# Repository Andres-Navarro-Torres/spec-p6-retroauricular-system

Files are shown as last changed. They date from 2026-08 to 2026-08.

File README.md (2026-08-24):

# SPEC-P6: An Open-Source, Modular, and Synchronized Wearable Sensor Platform



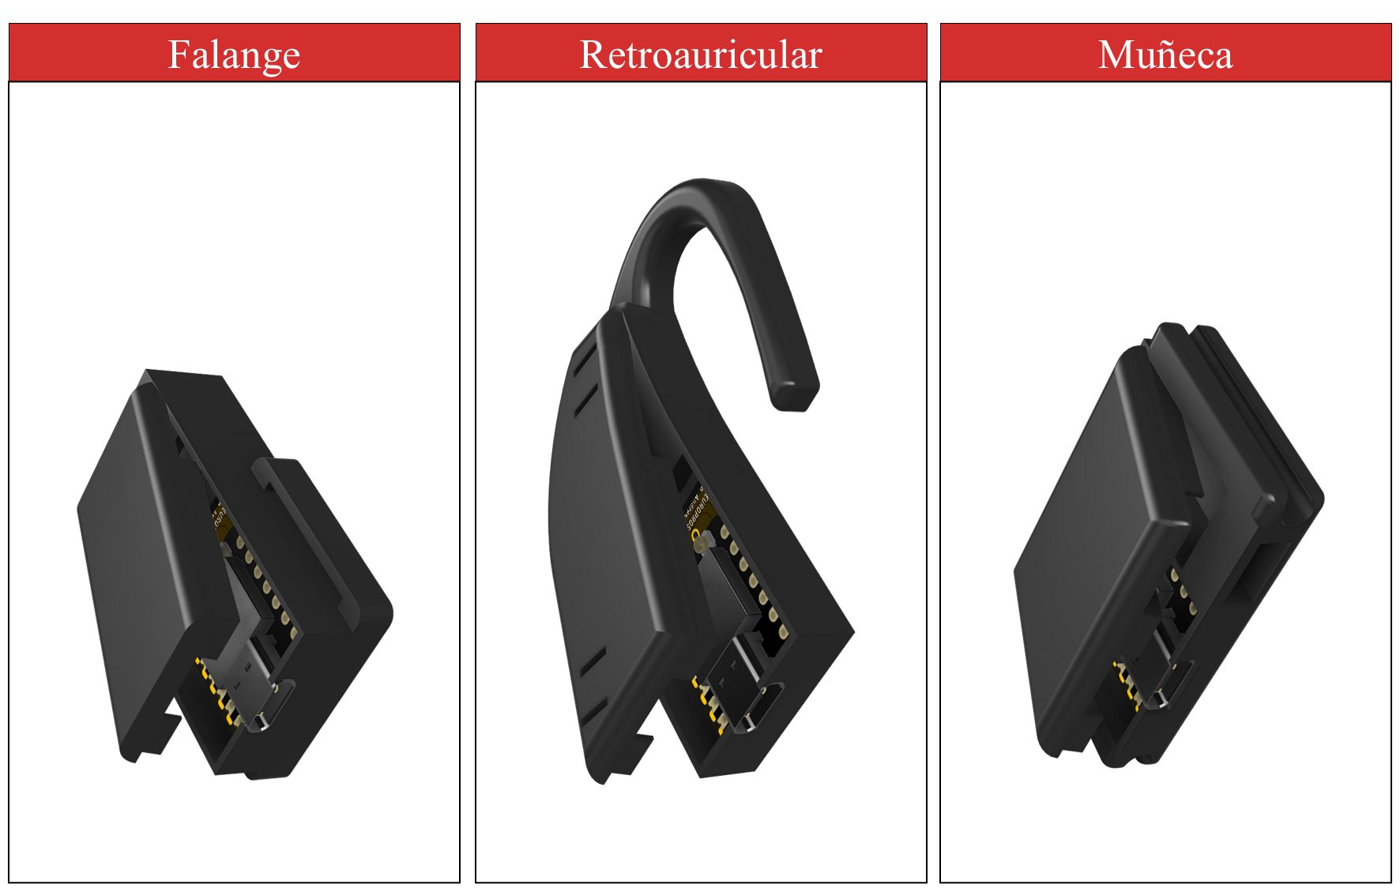
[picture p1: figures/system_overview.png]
SPEC-P6 System Overview
 

## Overview

SPEC-P6 is an open-source, reproducible, and modular wearable platform designed for simultaneous, multi-site acquisition of photoplethysmography (PPG) and inertial measurement unit (IMU) data. The system enables synchronized telemetry across multiple anatomical locations (specifically configured for the retroauricular region, wrist, and index finger) using a wireless star network architecture.

## System Architecture

The platform operates under a star network topology where a central Coordinator gathers data packets from multiple wearable Sensor Nodes via ESP-NOW and forwards them to a host computer through a high-speed serial link:

`PC (Python GUI) <-> Serial (921,600 baud) <-> Coordinator (ESP32) <-> ESP-NOW <-> Sensor Nodes (XIAO ESP32-C6)`

- **Sensor Node (Custom Hardware):** A compact custom PCB integrating a Seeed Studio XIAO ESP32-C6, a MAX30102 PPG sensor, an MPU6050 6-axis IMU, LDO voltage regulators, a 3.7V 100 mAh LiPo battery, and power management switches.
- **Coordinator (Functional Role):** A standard COTS ESP32 development board running firmware that bridges wireless ESP-NOW telemetry to a serial stream. It also provides a hardware digital/TTL synchronization trigger (Pin 2) for precise time-alignment with external DAQ systems (e.g., BIOPAC).

## Repository Structure

The repository is organized into the following directories:

- `/hardware/`: Contains custom PCB Gerber files, EAGLE source files (`.sch`, `.brd`), and the detailed Bill of Materials (BOM) with manufacturer part numbers.
- `/mechanical/`: Includes 3D printable `.STL` files and editable CAD source files for the wearable enclosures across all targeted anatomical sites.
- `/firmware/`: Houses the C/C++ source code for the Sensor Nodes and the Coordinator, alongside shared MAC address definitions.
- `/software/`: Contains the Python-based graphical acquisition suite (`spec_p6_acquisition_suite.py`), battery logging utilities, and `requirements.txt`. The GUI utilizes PyQt6 and PyQtGraph for high-performance rendering, and SciPy for real-time digital filtering of the raw signals.
- `/documentation/`: Contains printing guidelines (`PRINTING_SETTINGS.md`) and component assembly instructions.
- `/figures/`: High-resolution images of the hardware, GUI screenshots, and in-vivo placement examples.
- `/protocols/`: Markdown files describing acquisition, communication, and synchronization procedures.
- `/validation/`: Includes a sample dataset (`.csv`) for script testing and battery discharge logs.

## Key Technical Specifications

- **Target Sampling Rate:** 50 Hz steady for both PPG and IMU streams.
- **Wireless Protocol:** ESP-NOW (packaged in batches of 5 samples per transmission to optimize network bandwidth).
- **Concurrency:** FreeRTOS-based multitasking on the ESP32-C6 core for robust sensor polling and transmission without timing jitter.
- **Battery Life:** ~58 minutes of continuous multi-sensor transmission on a 100 mAh LiPo cell.
- **Timing Performance:** Low jitter (< 0.6 ms) and zero packet loss under standard laboratory testing conditions.

## Quick Start & Reproduction Guide

To deploy and operate the SPEC-P6 platform:

1. **Hardware Fabrication:** Order the PCB using the Gerber files in `/hardware/` and assemble following the BOM guidelines.
2. **Firmware Flashing:** 
   - Flash `coordinator.ino` onto your Coordinator ESP32 device.
   - Flash `sensor_node.ino` onto your XIAO ESP32-C6 nodes, ensuring MAC addresses are correctly mapped in the firmware definitions.
3. **Mechanical Enclosures:** Print the 3D cases located in `/mechanical/STL_files/`. Refer to `/documentation/PRINTING_SETTINGS.md` for specific Bambu Lab slicing parameters (TPU/PETG recommendations).
4. **Software Execution:** 
   - Install Python dependencies via `pip install -r software/requirements.txt`.
   - Run the acquisition suite using `python software/spec_p6_acquisition_suite.py`.

## How to Cite

If you use SPEC-P6 in your academic research, please cite it using the repository's DOI:

> Navarro-Torres, A., Rosas-Agraz, F., Vélez-Pérez, H. A., Romo-Vázquez, R., & Guzmán-Quezada, E. E. (2026). SPEC-P6: An open-source synchronized wearable platform for multisite photoplethysmography and inertial sensing. Zenodo. https://doi.org/10.5281/zenodo.22048827

See the `CITATION.cff` file for more details.

## License

To effectively cover both the software and physical hardware designs, this project employs a dual-licensing strategy:

- **Software and Firmware:** Licensed under the [MIT License](LICENSE-SOFTWARE).
- **Hardware and Mechanical Designs:** Licensed under the CERN Open Hardware Licence Version 2 - Weakly Reciprocal (CERN-OHL-W-v2). You may redistribute and modify the hardware documentation under the terms of the CERN-OHL-W v2 (https://ohwr.org/cernohl).

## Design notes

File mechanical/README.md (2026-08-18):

# Mechanical Enclosures

## Overview
This directory contains the 3D CAD files and ready-to-print STL files for the SPEC-P6 Sensor Node enclosures. The designs are optimized for fused deposition modeling (FDM) 3D printers and feature specific ergonomic curves for three anatomical sites:
1. Retroauricular (Behind the ear)
2. Wrist
3. Index Finger

## 3D Printing Parameters
To ensure structural integrity, a proper friction-fit for the internal electronics, and optimal sensor performance, the following printing parameters are recommended (tested on Bambu Lab printers):

- **Material:** The designs were originally optimized for **PLA (Polylactic Acid)**. However, if higher mechanical resistance, firmness, or thermal stability is required, materials like PETG or ABS can be used according to the researcher's preference.
- **Color (CRITICAL):** It is highly recommended to use **Black or very dark-colored filaments**. Light or translucent colors allow ambient light to penetrate the casing and refract inside, which causes severe optical interference with the MAX30102 PPG sensor. Dark materials effectively absorb ambient light, ensuring high signal quality.
- **Layer Height:** 0.12 mm or 0.16 mm (crucial for the snap-fit tolerances and smooth surface finish).
- **Infill:** 20% to 30% (Gyroid or Grid pattern).
- **Supports:** Required only for the overhanging clips on the index finger model. The wrist and retroauricular cases are designed to print flat without supports.
- **Wall Loops:** 3 (to protect the internal electronics and improve optical isolation).

## Files Included
- `/STL_Files/`: Exported mesh files, ready to be sliced in software like Bambu Studio or Ultimaker Cura.
- `/CAD_Source/`: Original parametric files (e.g., Fusion 360 .f3d or .step) to allow researchers to modify the enclosures for different battery sizes or anatomical variations.

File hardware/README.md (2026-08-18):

# Hardware Design Files

## Overview
This directory contains all the electronic design automation (EDA) files required to manufacture the SPEC-P6 Sensor Node custom PCB. 

## PCB Specifications
- **Dimensions:** 22.07 mm x 27.54 mm
- **Layers:** 2-layer rigid FR4
- **Thickness:** 1.6 mm
- **Solder Mask:** Black

## Assembly Strategy (PCBA)
The PCB is designed for a hybrid assembly approach to drastically reduce automated manufacturing costs:
1. **Bottom Layer (SMT):** All surface-mount components (MAX30102, MPU6050, LDO regulators, and passives) are placed on the bottom layer. This layer is designed to be fully assembled by automated pick-and-place machines (e.g., JLCPCB SMT Service).
2. **Top Layer (Manual/THT):** The top layer is reserved for the Seeed Studio XIAO ESP32-C6 microcontroller, the battery slide switch, and the optional tactile button. These components are soldered manually via castellated holes or through-hole pads.

## Files Included
- `SPEC-P6_Schematic.pdf`: The electrical circuit diagram.
- `SPEC-P6_BOM.xlsx`: The Bill of Materials, including exact LCSC part numbers and cost breakdowns for single-node and full-system reproduction.
- `/Gerbers/`: The standard RS-274X Gerber zip file ready to be uploaded to any PCB manufacturer.

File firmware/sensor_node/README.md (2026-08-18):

# SPEC-P6 Sensor Node

## Description

The SPEC-P6 Sensor Node is the wearable multisensor acquisition unit developed for simultaneous photoplethysmographic (PPG) and inertial measurement.

Each Sensor Node integrates:

- XIAO ESP32-C6 microcontroller
- MAX30102 photoplethysmography sensor
- MPU6050 inertial measurement unit (IMU)
- Custom-designed PCB (2-layer, 1.6 mm thickness)
- 3.7 V, 100 mAh LiPo battery
- Power slide switch and user tactile push-button

The same Sensor Node hardware is used for the three anatomical measurement sites: retroauricular region, wrist, and index finger.

## Main functions

The Sensor Node:

1. Acquires PPG data from the MAX30102 sensor via I2C.
2. Acquires inertial data (accelerometer and gyroscope) from the MPU6050 via I2C.
3. Generates high-resolution device timestamps using FreeRTOS timer ticks.
4. Packages five samples into structured ESP-NOW data packets to optimize wireless bandwidth.
5. Transmits data wirelessly to the Coordinator using ESP-NOW in a star network topology.
6. Receives control commands from the Coordinator (Start, Stop, and Calibration routines).
7. Monitors and reports battery voltage through an integrated ADC voltage divider.

## Firmware & FreeRTOS Architecture

The firmware is built on FreeRTOS for concurrent multitasking and real-time management:

- Dedicated task handling inertial data acquisition.
- Dedicated task handling PPG FIFO reading and polling.
- Dedicated task monitoring battery voltage status.
- Hardware abstraction and shared protocol definitions managed through common_definitions.h.

## Sampling

The target acquisition rate is 50 Hz for PPG and inertial measurements.

Five samples are grouped into each data packet before wireless transmission.

## Communication

Communication with the Coordinator is performed using ESP-NOW over Wi-Fi STA mode (channel configured via common definitions).

The Sensor Node transmits structured data packets to the Coordinator and listens for incoming control packets.

## Hardware documentation

The complete hardware design, including PCB files, schematic, Gerber files, and bill of materials, is available in:

/hardware/sensor_node/

## Configuration

Network configuration parameters, device MAC addresses, and operational constants are defined in the shared firmware definitions file:

/firmware/common/common_definitions.h

## Reproduction

To reproduce a Sensor Node:

1. Manufacture the custom FR4 PCB using the provided Gerber files.
2. Solder the surface-mount components (bottom layer SMT assembly) and assemble the XIAO ESP32-C6 microcontroller and auxiliary switches (top layer).
3. Connect the 3.7V 100 mAh LiPo battery and power switch.
4. Program the XIAO ESP32-C6 with the Sensor Node firmware (sensor_node.ino).
5. Configure the ESP-NOW network parameters and MAC addresses in common_definitions.h.
6. Verify wireless communication and calibration with the Coordinator.
7. Verify PPG and IMU acquisition before final mechanical casing integration.

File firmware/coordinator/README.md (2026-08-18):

# SPEC-P6 Coordinator

## Description

The SPEC-P6 Coordinator is the ESP32-based communication and acquisition gateway responsible for coordinating multiple Sensor Nodes.

The Coordinator is a functional role rather than a dedicated SPEC-P6 PCB. It can be implemented using a compatible ESP32 device with ESP-NOW support.

## Main functions

The Coordinator:

1. Communicates with multiple SPEC-P6 Sensor Nodes using ESP-NOW.
2. Sends control commands to the Sensor Nodes.
3. Receives measurement packets from the Sensor Nodes.
4. Forwards acquired data to the host computer through a serial interface.
5. Provides the interface between the wireless sensor network and the acquisition software.
6. Generates the synchronization trigger used for integration with external DAQ systems (e.g., BIOPAC).

## Network architecture

The system uses a star topology:

Coordinator
- Sensor Node 1
- Sensor Node 2
- Sensor Node 3

Sensor Nodes transmit measurement data to the Coordinator.

The Coordinator can transmit control commands to the Sensor Nodes.

## Hardware

The Coordinator does not require a dedicated SPEC-P6 PCB.

Any compatible ESP32 platform capable of ESP-NOW communication may be used, provided that the required firmware interfaces and synchronization output are available.

## Communication

Wireless communication is performed using ESP-NOW.

The host computer communicates with the Coordinator through a serial connection.

## Serial interface

The current acquisition system uses a serial communication rate of 921,600 baud.

## Synchronization

The Coordinator provides the hardware synchronization interface (Pin 2 digital output) used to generate the external synchronization trigger.

## Configuration

ESP-NOW network parameters and device addresses are defined in:

/firmware/common/common_definitions.h

## Reproduction

To reproduce the Coordinator:

1. Select a compatible ESP32 device with ESP-NOW support.
2. Configure the network parameters in common_definitions.h.
3. Upload the Coordinator firmware (coordinator.ino).
4. Configure the Sensor Node MAC addresses.
5. Connect the Coordinator to the host computer via USB (921,600 baud).
6. Verify wireless communication with the Sensor Nodes.
7. Verify the synchronization output before experimental acquisition.

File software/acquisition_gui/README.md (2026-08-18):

# SPEC-P6 Acquisition Software

## Overview

The SPEC-P6 Acquisition Software is a high-performance Python-based graphical user interface developed for real-time monitoring, visualization, synchronization, and data logging from the SPEC-P6 wearable sensor network.

The software interfaces directly with the SPEC-P6 Coordinator via a high-speed serial link.

## Main functions

The application provides:

- Real-time multi-channel visualization of photoplethysmography (PPG) signals (IR and RED channels) with optional bandpass filtering and moving-window display.
- Real-time visualization of 6-axis inertial measurement unit (IMU) data (accelerometer and gyroscope).
- Live monitoring of connected Sensor Nodes, packet health, and battery voltage status.
- Centralized acquisition control (Start, Stop, and Calibration commands).
- Automated sensor calibration and signal quality index (SQI) evaluation.
- Instantaneous and moving-average sampling-frequency estimation (Fs).
- Heart-rate (HR) estimation via Welch's method and spectral power density (PSD) monitoring.
- Synchronized multi-node data recording and structured CSV data export.
- Universal hardware synchronization via an external digital/TTL trigger output (compatible with standard DAQ systems or reference instruments).

## System communication

The communication architecture follows a star topology where the host computer links to a central Coordinator, which in turn communicates wirelessly with multiple Sensor Nodes via ESP-NOW:

PC (Python GUI) <-> Serial (921,600 baud) <-> Coordinator (ESP32) <-> ESP-NOW <-> Sensor Nodes (XIAO ESP32-C6)

The current implementation utilizes a high-speed serial communication rate of 921,600 baud between the host computer and the Coordinator.

## Data acquisition and packet structure

The software receives aggregated data packets from the Coordinator and maintains independent ring buffers (RingBuffer) for each active Sensor Node. 

The target acquisition frequency is 50 Hz. Each received measurement sample contains:

- High-resolution device timestamp (DeviceTimestamp_us).
- PPG Red channel intensity.
- PPG Infrared (IR) channel intensity.
- Accelerometer data (Ax, Ay, Az).
- Gyroscope data (Gx, Gy, Gz).
- Instantaneous sampling frequency estimate (Instant_Fs_Hz).
- Node battery voltage (Battery_mV and estimated percentage).

## Calibration and synchronization protocol

Before starting an official recording session, the software manages an automated protocol:

1. Calibration Trigger: The interface sends a calibration command (3) to the nodes via the Coordinator.
2. Sensor Check: Verifies optical coupling (finger/skin detection threshold) and adjusts LED power dynamically.
3. Grace Period & Alignment: Listens for incoming nodes during a grace period (JOIN_GRACE_SECONDS) and synchronizes timestamps across all active devices.
4. TTL Trigger Activation: Automatically fires a digital TTL pulse (setting Coordinator Pin 2 HIGH) to trigger external DAQ equipment at the exact start of valid data recording.
5. Continuous Logging & Preview: Buffers data, displays a real-time preview upon completion, and allows final export to structured CSV files.

## Data output

The software exports synchronized data as structured CSV files containing multi-column telemetry for all connected nodes, including precise timing, physiological signals, inertial dynamics, and system metadata.

## Requirements

The software requires Python 3.x and the dependency packages listed in requirements.txt:

- PyQt6 (Graphical interface framework)
- pyqtgraph (High-performance real-time plotting)
- numpy (Numerical computations and buffer management)
- scipy (Signal processing, filtering, and Welch PSD estimation)
- pyserial (Serial port communication handling)
- openpyxl (Spreadsheet and Excel file management)

## Installation

Install the required Python dependencies by running:

    pip install -r requirements.txt

## Execution

Run the acquisition software suite with:

    python spec_p6_acquisition_suite.py

## Hardware requirements

Running this software requires:

- A SPEC-P6 Coordinator (standard ESP32 development board running coordinator.ino).
- One or more SPEC-P6 Sensor Nodes (custom PCB based on Seeed Studio XIAO ESP32-C6 running sensor_node.ino).
- A USB-C to USB-A cable connecting the Coordinator to the host PC (operating at 921,600 baud).
- Optional: An external DAQ system connected via a digital TTL cable to the Coordinator’s sync pin (Pin 2).

## Notes

This software is designed to operate seamlessly alongside the SPEC-P6 firmware and communication protocol framework. 

For hardware schematics, PCB files, mechanical CAD/STL enclosures, and firmware sources, refer to the root repository documentation.

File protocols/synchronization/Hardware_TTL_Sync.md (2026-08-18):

# Synchronization and Latency Protocol

## Overview
Synchronizing wireless sensor networks with external "Gold Standard" Data Acquisition systems (e.g., BIOPAC) is critical for clinical validation. The SPEC-P6 platform implements a hardware-level digital trigger to guarantee temporal alignment between the wireless telemetry and external reference instruments.

## Hardware Synchronization (TTL Trigger)
The Coordinator firmware is designed to emit a discrete hardware signal marking the exact start of a recording session:
- **Pin Output:** Digital Pin 2 on the Coordinator ESP32.
- **Signal Logic:** 3.3V TTL (Active HIGH).
- **Mechanism:** When the Python GUI issues the Start Recording command, the Coordinator brings Pin 2 HIGH. This pulse is wired directly to a digital input channel on the external DAQ. By aligning the rising edge of the TTL pulse in the external DAQ with the first recorded packet in the SPEC-P6 CSV file, both systems share an absolute time zero ($t_0$).

## Software Synchronization (Grace Period)
To ensure all nodes begin streaming simultaneously:
1. The Coordinator broadcasts a Start command.
2. The network enters a `JOIN_GRACE_SECONDS` window.
3. Timestamps on all nodes are reset, ensuring the first recorded sample across the retroauricular, wrist, and finger nodes shares the exact same baseline.

---

## Validation: The "Tap Test" Protocol
To quantify the end-to-end latency (jitter and delay) of the ESP-NOW transmission, a physical "Tap Test" must be performed in the laboratory.

### Setup Requirements
1. **SPEC-P6 Node:** Powered on and communicating with the GUI.
2. **External DAQ (e.g., BIOPAC):** Equipped with a contact microphone or analog accelerometer, and connected to the Coordinator's TTL sync pin.
3. **Physical Alignment:** Secure the SPEC-P6 node and the DAQ analog sensor to the same rigid surface (e.g., a wooden desk).

### Execution Steps
1. Initiate recording on the external DAQ.
2. Click "Start Acquisition" on the SPEC-P6 Python GUI (This fires the TTL pulse, marking $t_0$ on the DAQ).
3. Using a rigid object (e.g., a pen), deliver three (3) sharp, distinct physical taps to the desk surface near the sensors, leaving approximately 2 seconds between each tap.
4. Stop both recordings.

### Analysis
By comparing the temporal distance between $t_0$ and the three acceleration spikes in the external DAQ software versus the SPEC-P6 CSV output, the absolute transmission latency can be calculated.

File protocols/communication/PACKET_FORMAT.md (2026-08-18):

# Packet Format and Data Batching

## Overview
Transmitting a wireless packet for every single sensor reading (50 times per second) is highly inefficient and severely degrades battery life due to radio overhead. To solve this, the SPEC-P6 Sensor Nodes implement a data batching strategy before transmitting the ESP-NOW payload.

## Batching Strategy
- **Target Sampling Rate:** 50 Hz (1 sample every 20 ms).
- **Batch Size:** 5 samples per wireless packet.
- **Transmission Rate:** 10 packets per second (10 Hz).

By grouping 5 samples into a single payload, the radio transmitter is active only 10 times per second, significantly reducing power consumption while maintaining the high-resolution 50 Hz temporal data string.

## ESP-NOW Payload Structure
The maximum payload size for ESP-NOW is 250 bytes. The SPEC-P6 data packet is designed to fit comfortably within this limit.

### 1. Packet Header
Every transmitted packet begins with metadata for network management:
- `Node_ID` (uint8_t): Identifies the anatomical source (e.g., 1=Finger, 2=Wrist, 3=Retroauricular).
- `Packet_Counter` (uint32_t): An incrementing integer to track packet loss or out-of-order deliveries.
- `Battery_Level` (uint16_t): The current battery voltage in millivolts.

### 2. Data Frames (Array of 5)
Following the header, the packet contains an array of 5 `SensorFrame` structures. Each frame represents a single 20 ms snapshot containing:
- `DeviceTimestamp_us` (uint32_t): Microsecond precision FreeRTOS tick.
- `PPG_Red` (uint32_t): MAX30102 Red channel intensity.
- `PPG_IR` (uint32_t): MAX30102 Infrared channel intensity.
- `Accel_X, Accel_Y, Accel_Z` (int16_t x 3): MPU-6050 Acceleration vectors.
- `Gyro_X, Gyro_Y, Gyro_Z` (int16_t x 3): MPU-6050 Angular velocity vectors.

Upon receiving this structured payload, the Coordinator unpacks the 5 frames and streams them individually over the serial port to the Python interface, reconstructing the continuous 50 Hz signal.

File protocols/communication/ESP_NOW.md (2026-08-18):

# ESP-NOW Communication Protocol

## Overview
To achieve high-speed, low-latency, and connectionless data transfer, the SPEC-P6 platform utilizes the Espressif ESP-NOW protocol. This protocol operates over the 2.4 GHz Wi-Fi spectrum but strips away the overhead of standard TCP/IP connections, making it ideal for real-time wearable sensor networks.

## Network Topology
The system employs a deterministic **Star Topology**:
- **Hub (Receiver):** The Coordinator (ESP32) acts as the central receiver, listening for incoming data on a specific Wi-Fi channel.
- **Spokes (Transmitters):** Up to three Sensor Nodes (XIAO ESP32-C6) act as the transmitters, located at the retroauricular region, wrist, and index finger.

## Configuration and Addressing
Unlike standard Wi-Fi that uses IP addresses, ESP-NOW routes packets using hardware MAC addresses.
- **Station Mode:** All devices (Coordinator and Nodes) must be configured in Wi-Fi Station (`WIFI_STA`) mode.
- **MAC Pairing:** The MAC address of the Coordinator is hardcoded into the Sensor Nodes' firmware via `common_definitions.h` to ensure packets are routed strictly to the host receiver.
- **Channel Synchronization:** Both the sender and receiver must operate on the exact same Wi-Fi channel (default is Channel 1).

## Advantages for SPEC-P6
- **Reduced Power Consumption:** Nodes wake up, transmit the payload, and return to sensor polling immediately without waiting for complex TCP handshakes.
- **Low Latency:** Data reaches the Coordinator in fractions of a millisecond.
- **Scalability:** Additional nodes can be added to the network simply by pointing their transmission logic to the Coordinator's MAC address.

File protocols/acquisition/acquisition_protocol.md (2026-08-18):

# Acquisition Protocol

## Overview
This document details the data acquisition methodology implemented in the SPEC-P6 Sensor Nodes. The firmware is designed to capture high-fidelity physiological and inertial data using a deterministic, FreeRTOS-based architecture on the XIAO ESP32-C6 microcontroller.

## Sensor Interfaces
The SPEC-P6 node interfaces with two primary sensors over the I2C bus:
1. **MAX30102 (Photoplethysmography - PPG):** Configured to acquire RED and IR optical absorption signals.
2. **MPU-6050 (Inertial Measurement Unit - IMU):** Configured to acquire 3-axis acceleration and 3-axis angular velocity.

Both sensors operate on the same I2C bus, managed through the ESP32-C6 I2C peripheral. A PCA9306 logic level translator ensures safe communication between the 3.3V logic of the MCU/IMU and the 1.8V bus requirement of the MAX30102.

## Sampling Rate and Timing
- **Target Sampling Frequency (Fs):** 50 Hz.
- **Timing Mechanism:** High-resolution device timestamps (`DeviceTimestamp_us`) are generated using native FreeRTOS timer ticks. This ensures that every sample is logged with precise temporal spacing, completely independent of wireless transmission delays.

## FreeRTOS Task Architecture
To prevent I2C bus collisions and maintain a strict 50 Hz sampling rate, the firmware utilizes isolated FreeRTOS tasks:
- **Acquisition Task:** Runs with high priority. It polls the MPU-6050 registers and reads the MAX30102 FIFO buffer exactly every 20 milliseconds.
- **System Task:** Runs with lower priority. It monitors battery voltage via the internal ADC and manages LED state indications.

## Data Structure
A single data frame acquired at each 20 ms tick contains:
- 1x 32-bit Timestamp (Microseconds)
- 1x 32-bit PPG RED value
- 1x 32-bit PPG IR value
- 3x 16-bit Accelerometer values (X, Y, Z)
- 3x 16-bit Gyroscope values (X, Y, Z)
- 1x 16-bit Battery measurement

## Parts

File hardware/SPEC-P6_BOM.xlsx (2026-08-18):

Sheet: Sensor Node
Designator | Description | Footprint | Source / Part Number | Qty | Unit Cost (USD) | Total Cost (USD)
U1 | MAX30102EFD+T (PPG Sensor) | 14-OESIP | LCSC C6454833 | 1 | 14.54 | 14.54
U2 | MPU-6050 (6-Axis IMU) | QFN-24 | LCSC C24112 | 1 | 15.03 | 15.03
U5 | PCA9306DCUT (I2C Level Translator) | VSSOP-8 | LCSC C353162 | 1 | 0.49 | 0.49
U3 | AP2112K-3.3TRG1 (3.3V LDO Regulator) | SOT-23-5 | LCSC C23380830 | 1 | 0.11 | 0.11
U4 | XC6206P182MR (1.8V LDO Regulator) | SOT-23 | LCSC C5252894 | 1 | 0.02 | 0.02
C1 | 10 µF Capacitor (10V, X5R) | 0603 | LCSC C19702 | 1 | 0.04 | 0.04
C2, 3, 9, 11, 13, 14 | 0.1 µF Capacitor (50V, X7R) | 0603 | LCSC C57112 | 6 | 0.01 | 0.06
C4 | 4.7 µF Capacitor (25V, X5R) | 0603 | LCSC C69335 | 1 | 0.05 | 0.05
C5, C6, C7, C8 | 1 µF Capacitor (25V, X7R) | 0603 | LCSC C29936 | 4 | 0.02 | 0.08
C10 | 0.01 µF Capacitor (50V, X7R) | 0603 | LCSC C1589 | 1 | 0.01 | 0.01
C12 | 2200 pF Capacitor (50V, X7R) | 0603 | LCSC C1604 | 1 | 0.02 | 0.02
R1, R2, R4, R5 | 4.7 kΩ Resistor (100mW) | 0603 | LCSC C23162 | 4 | 0.01 | 0.04
R3, R7 | 47 kΩ Resistor (100mW) | 0603 | LCSC C25811 | 2 | 0.01 | 0.02
R6, R8 | 3.3 kΩ Resistor (100mW) | 0603 | LCSC C22978 | 2 | 0.01 | 0.02
MCU | XIAO ESP32-C6 (Seeed Studio) | Castellated/DIP | Seeed / Mouser | 1 | 5 | 5
BATT | 3.7V 100 mAh LiPo Battery | JST/Pad | Generic | 1 | 3 | 3
SW_PWR | SPDT Slide Switch (ON/OFF) | SMD / Mini THT | LCSC / Generic | 1 | 0.25 | 0.25
SW_USR | SMD Push Button (User/Reset) | SMD 3x4x2 mm | LCSC / Generic | 1 | 0.1 | 0.1
PCB | Custom FR4 PCB (22.07 x 27.54 mm) | 2-layer, 1.6 mm | JLCPCB | 1 | 0.4 | 0.4
CASE | 3D Printed Case (PLA/PETG/TPU) | Custom | Bambu Lab | 1 | 0.5 | 0.5
 | Total Unit Cost (1x Sensor Node) |  |  |  |  | 39.78

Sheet: Full System
Module / Component | Type | Function in Platform | Qty | Unit Cost (USD) | Total Cost (USD)
SPEC-P6 Sensor Node | Custom Hardware | Wearable nodes (Retroauricular, Wrist, Finger) | 3 | 39.78 | 119.34
Coordinator Node | COTS | ESP-NOW to Serial Bridge + Universal TTL Sync Trigger | 1 | 5.5 | 5.5
USB-C to USB-A Cable | COTS Accessory | PC-Coordinator Serial Link (921,600 baud) | 1 | 2.5 | 2.5
TTL Sync Cable | Wired Link | Pin 2 (Coordinator) to DAQ Digital Input (e.g., BIOPAC) | 1 | 1 | 1
 |  | Total Full System Cost |  |  | 128.34

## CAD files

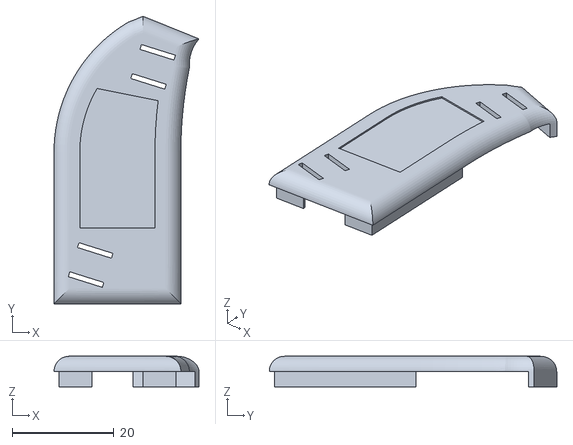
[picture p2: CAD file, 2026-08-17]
mechanical/STL_Files/SPEC-P6_Enclosure_Retroauricular_Cover.stl
28.5 x 56.5 x 6.00

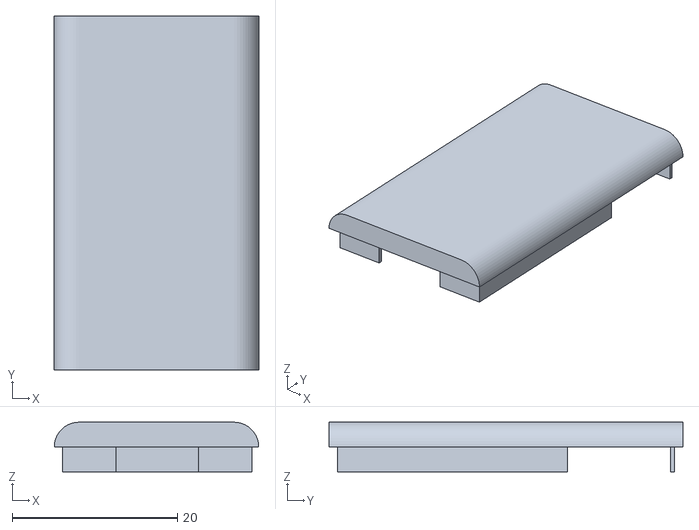
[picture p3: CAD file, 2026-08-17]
mechanical/STL_Files/SPEC-P6_Enclosure_Finger_cover.stl
24.7 x 42.8 x 6.00

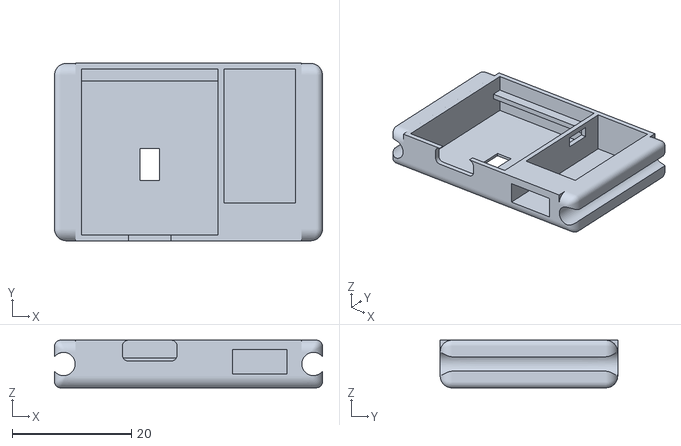
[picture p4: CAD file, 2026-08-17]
mechanical/STL_Files/SPEC-P6_Enclosure_Wrist_base.stl
45.0 x 29.8 x 8.00

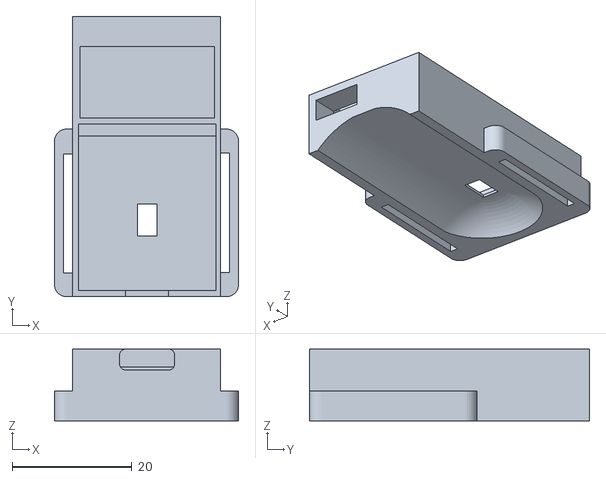
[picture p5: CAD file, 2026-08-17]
mechanical/STL_Files/SPEC-P6_Enclosure_Finger_base.stl
30.7 x 46.8 x 12.0

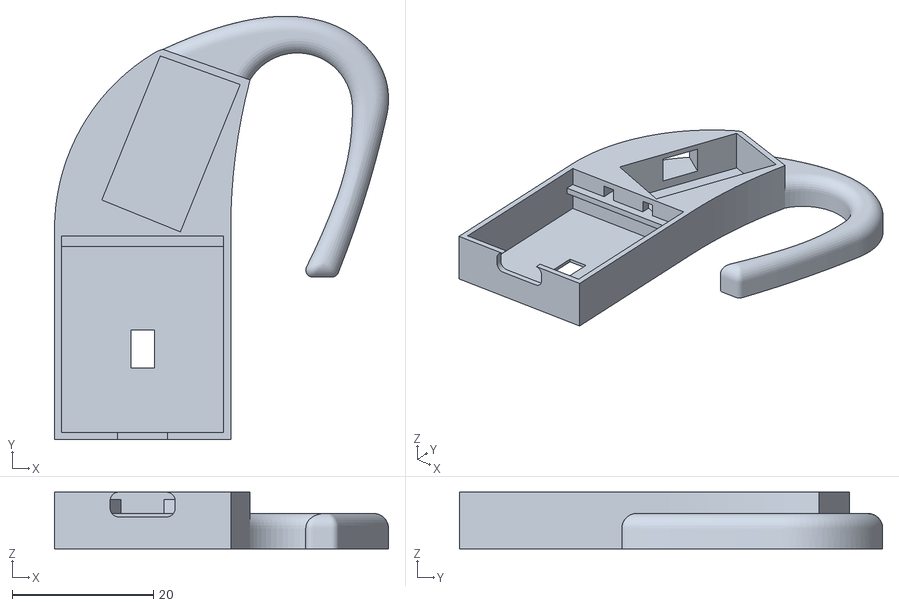
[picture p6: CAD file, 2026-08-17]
mechanical/STL_Files/SPEC-P6_Enclosure_Retroauricular_Base.stl
47.3 x 59.9 x 8.00

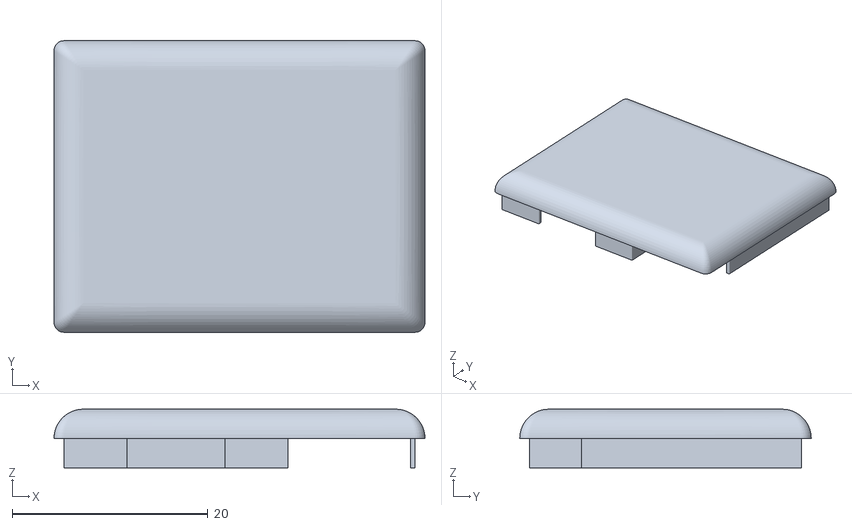
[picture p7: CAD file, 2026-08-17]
mechanical/STL_Files/SPEC-P6_Enclosure_Wrist_Cover.stl
37.9 x 29.8 x 6.00

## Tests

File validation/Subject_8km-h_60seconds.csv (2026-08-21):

SlaveID_Slave1_Retroauricular | Timestamp_us_Slave1_Retroauricular | Red_Slave1_Retroauricular | IR_Slave1_Retroauricular | Ax_Slave1_Retroauricular | Ay_Slave1_Retroauricular | Az_Slave1_Retroauricular | Gx_Slave1_Retroauricular | Gy_Slave1_Retroauricular | Gz_Slave1_Retroauricular | Instant_Fs_Hz_Slave1_Retroauricular | DeviceTimestamp_us_Slave1_Retroauricular | SlaveID_Slave2_Muneca | Timestamp_us_Slave2_Muneca | Red_Slave2_Muneca | IR_Slave2_Muneca | Ax_Slave2_Muneca | Ay_Slave2_Muneca | Az_Slave2_Muneca | Gx_Slave2_Muneca | Gy_Slave2_Muneca | Gz_Slave2_Muneca | Instant_Fs_Hz_Slave2_Muneca | DeviceTimestamp_us_Slave2_Muneca | SlaveID_Slave3_Dedoindice | Timestamp_us_Slave3_Dedoindice | Red_Slave3_Dedoindice | IR_Slave3_Dedoindice | Ax_Slave3_Dedoindice | Ay_Slave3_Dedoindice | Az_Slave3_Dedoindice | Gx_Slave3_Dedoindice | Gy_Slave3_Dedoindice | Gz_Slave3_Dedoindice | Instant_Fs_Hz_Slave3_Dedoindice | DeviceTimestamp_us_Slave3_Dedoindice
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

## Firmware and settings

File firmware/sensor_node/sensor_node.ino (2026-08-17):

/**
 * @file slave_node.ino
 * @author Andrés Navarro
 * @brief Slave Node Firmware - SPEC-P6 System
 * @details Firmware for the ESP32-C6 slave node. Responsible for sampling 
 *          retroauricular photoplethysmography (MAX30102) and inertial 
 *          data (MPU6050) under movement dynamics, utilizing FreeRTOS 
 *          tasks and ESP-NOW communication.
 * @institution Universidad de Guadalajara (UdeG) - CUCEI
 * @date 2026
 */

#include <esp_now.h>
#include <WiFi.h>
#include <esp_wifi.h>
#include "esp_bt.h" 
#include "common_definitions.h" 
#include <Wire.h>
#include "freertos/FreeRTOS.h"
#include "freertos/semphr.h"

#define MAX30102_ADDRESS        0x57
#define MAX_REG_MODE_CONFIG     0x09
#define MAX_REG_SPO2_CONFIG     0x0A
#define MAX_REG_FIFO_CONFIG     0x08
#define MAX_REG_PART_ID         0xFF
#define MAX_REG_FIFO_WR_PTR     0x04
#define MAX_REG_FIFO_RD_PTR     0x06
#define MAX_REG_FIFO_DATA       0x07
#define MAX_REG_LED1_PA         0x0C 
#define MAX_REG_LED2_PA         0x0D 

#define MPU6050_ADDRESS         0x68
#define MPU_REG_SMPLRT_DIV      0x19
#define MPU_REG_CONFIG          0x1A 
#define MPU_REG_GYRO_CONFIG     0x1B
#define MPU_REG_ACCEL_CONFIG    0x1C
#define MPU_REG_ACCEL_XOUT_H    0x3B
#define MPU_REG_PWR_MGMT_1      0x6B
#define MPU_REG_WHO_AM_I        0x75

#ifndef LED_BUILTIN
#define LED_BUILTIN 21
#endif

struct PpgData { int64_t timestamp; long red; long ir; };
struct MpuData { int16_t ax; int16_t ay; int16_t az; int16_t gx; int16_t gy; int16_t gz; };

MpuData mpuDataGlobal;

QueueHandle_t ppgQueue;
TaskHandle_t ppgTaskHandle;
TaskHandle_t mpuTaskHandle;
TaskHandle_t batteryTaskHandle;
SemaphoreHandle_t serialMutex;
SemaphoreHandle_t i2cMutex;
SemaphoreHandle_t mpuMutex;

volatile bool systemRunning = false;
volatile bool sensorsActive = false;
volatile int64_t timeOffset_us = 0;
volatile uint16_t batteryVoltage_mv = 0;

volatile uint8_t ledBrightness = 0x24; 
const long FINGER_DETECT_THRESH         = 20000;
const long BRIGHTNESS_ADJUST_LOW_THRESH  = 60000;
const long BRIGHTNESS_ADJUST_HIGH_THRESH = 150000;

struct_data_packet dataBatch; 
int64_t lastSampleTime = 0;
unsigned long ledTimer = 0; 
bool ledState = false;

bool writeRegister8(uint8_t address, uint8_t reg, uint8_t val) {
  Wire.beginTransmission(address); Wire.write(reg); Wire.write(val);
  return (Wire.endTransmission() == 0);
}

uint8_t readRegister8(uint8_t address, uint8_t reg, bool* success) {
  Wire.beginTransmission(address); Wire.write(reg);
  if (Wire.endTransmission(false) != 0) { *success = false; return 0; }
  if (Wire.requestFrom(address, (uint8_t)1) != 1) { *success = false; return 0; }
  *success = true; return Wire.read();
}

bool readBurst(uint8_t address, uint8_t reg, uint8_t* buffer, uint8_t count) {
  Wire.beginTransmission(address); Wire.write(reg);
  if (Wire.endTransmission(false) != 0) return false;
  if (Wire.requestFrom(address, count) != count) return false;
  for (int i = 0; i < count; i++) buffer[i] = Wire.read();
  return true;
}

void errorBlink() {
  pinMode(LED_BUILTIN, OUTPUT);
  while (1) {
    for (int i = 0; i < 3; i++) { digitalWrite(LED_BUILTIN, HIGH); delay(100); digitalWrite(LED_BUILTIN, LOW); delay(100); }
    delay(700);
  }
}

void mpuTask(void * pv) {
  uint8_t buf[14];
  for(;;) {
    if (sensorsActive) {
      if (xSemaphoreTake(i2cMutex, pdMS_TO_TICKS(50))) {
        if (readBurst(MPU6050_ADDRESS, MPU_REG_ACCEL_XOUT_H, buf, 14)) {
          xSemaphoreGive(i2cMutex);
          MpuData tmp;
          tmp.ax = (int16_t)(buf[0]  << 8 | buf[1]);
          tmp.ay = (int16_t)(buf[2]  << 8 | buf[3]);
          tmp.az = (int16_t)(buf[4]  << 8 | buf[5]);
          tmp.gx = (int16_t)(buf[8]  << 8 | buf[9]);
          tmp.gy = (int16_t)(buf[10] << 8 | buf[11]);
          tmp.gz = (int16_t)(buf[12] << 8 | buf[13]);
          xSemaphoreTake(mpuMutex, portMAX_DELAY);
          mpuDataGlobal = tmp;
          xSemaphoreGive(mpuMutex);
        } else {
          xSemaphoreGive(i2cMutex);
        }
      }
    }
    vTaskDelay(pdMS_TO_TICKS(20));
  }
}

void ppgTask(void * pv) {
  int64_t lastFifoReadTime = 0;
  bool haveReference = false;

  for (;;) {
    if (sensorsActive) {
      bool ok;
      if (xSemaphoreTake(i2cMutex, pdMS_TO_TICKS(5))) {
        uint8_t wr = readRegister8(MAX30102_ADDRESS, MAX_REG_FIFO_WR_PTR, &ok);
        uint8_t rd = readRegister8(MAX30102_ADDRESS, MAX_REG_FIFO_RD_PTR, &ok);
        int num = (int)wr - (int)rd; if (num < 0) num += 32;

        if (num > 0) {
          uint8_t b[6 * 32];
          if (readBurst(MAX30102_ADDRESS, MAX_REG_FIFO_DATA, b, num * 6)) {
            int64_t now = esp_timer_get_time() - timeOffset_us;
            int64_t spacing = haveReference ? (now - lastFifoReadTime) / num : 0;

            for (int i = 0; i < num; i++) {
              PpgData d;
              d.timestamp = haveReference ? (lastFifoReadTime + spacing * (i + 1)) : now;
              d.red = ((long)b[i*6+0] << 16 | (long)b[i*6+1] << 8 | (long)b[i*6+2]) & 0x03FFFF;
              d.ir  = ((long)b[i*6+3] << 16 | (long)b[i*6+4] << 8 | (long)b[i*6+5]) & 0x03FFFF;
              xQueueSend(ppgQueue, &d, 0);
            }
            lastFifoReadTime = now;
            haveReference = true;
          }
        }
        xSemaphoreGive(i2cMutex);
      }
    } else {
      haveReference = false;
    }
    vTaskDelay(pdMS_TO_TICKS(PPG_POLL_INTERVAL_MS));
  }
}

void batteryTask(void * pv) {
  pinMode(BATTERY_ADC_PIN, INPUT);
  for (;;) {
    uint32_t acc = 0;
    const int N = 16;
    for (int i = 0; i < N; i++) {
      acc += analogReadMilliVolts(BATTERY_ADC_PIN);
      delayMicroseconds(200);
    }
    uint16_t mv = (uint16_t)((acc / N) * BATTERY_DIVIDER_RATIO);
    batteryVoltage_mv = mv;
    vTaskDelay(pdMS_TO_TICKS(BATTERY_UPDATE_INTERVAL_MS));
  }
}

void runCalibration() {
  if (!xSemaphoreTake(serialMutex, portMAX_DELAY)) return;
  if (!xSemaphoreTake(i2cMutex, portMAX_DELAY)) { xSemaphoreGive(serialMutex); return; }

  writeRegister8(MAX30102_ADDRESS, MAX_REG_MODE_CONFIG, 0x03); 
  writeRegister8(MAX30102_ADDRESS, MAX_REG_LED1_PA, ledBrightness);
  writeRegister8(MAX30102_ADDRESS, MAX_REG_LED2_PA, ledBrightness);
  writeRegister8(MAX30102_ADDRESS, MAX_REG_FIFO_WR_PTR, 0x00);
  writeRegister8(MAX30102_ADDRESS, MAX_REG_FIFO_RD_PTR, 0x00);

  long irValue = 0;
  bool success;
  unsigned long startTime = millis();
  while (irValue < FINGER_DETECT_THRESH) {
    if (millis() - startTime > 10000) break; 
    uint8_t wr = readRegister8(MAX30102_ADDRESS, MAX_REG_FIFO_WR_PTR, &success);
    uint8_t rd = readRegister8(MAX30102_ADDRESS, MAX_REG_FIFO_RD_PTR, &success);
    int num = (int)wr - (int)rd; if (num < 0) num += 32;
    if (num > 0) {
      uint8_t buffer[6];
      readBurst(MAX30102_ADDRESS, MAX_REG_FIFO_DATA, buffer, 6);
      irValue = (long)buffer[3] << 16 | (long)buffer[4] << 8 | (long)buffer[5];
      irValue &= 0x03FFFF;
    }
    delay(100);
  }

  if (irValue >= FINGER_DETECT_THRESH) {
    bool brightnessOK = false;
    uint8_t currentBrightness = ledBrightness;
    if (currentBrightness < 0x10) currentBrightness = 0x10;
    for (int i = 0; i < 20 && !brightnessOK; i++) {
      writeRegister8(MAX30102_ADDRESS, MAX_REG_LED1_PA, currentBrightness);
      writeRegister8(MAX30102_ADDRESS, MAX_REG_LED2_PA, currentBrightness);
      writeRegister8(MAX30102_ADDRESS, MAX_REG_FIFO_WR_PTR, 0x00);
      writeRegister8(MAX30102_ADDRESS, MAX_REG_FIFO_RD_PTR, 0x00);
      delay(200);

      long totalIR = 0; int samplesRead = 0;
      startTime = millis();
      while(samplesRead < 5 && (millis() - startTime < 500)) {
        uint8_t wr = readRegister8(MAX30102_ADDRESS, MAX_REG_FIFO_WR_PTR, &success);
        uint8_t rd = readRegister8(MAX30102_ADDRESS, MAX_REG_FIFO_RD_PTR, &success);
        int num = (int)wr - (int)rd; if (num < 0) num += 32;
        if (num > 0) {
          uint8_t buffer[6];
          readBurst(MAX30102_ADDRESS, MAX_REG_FIFO_DATA, buffer, 6);
          long irVal = (long)buffer[3] << 16 | (long)buffer[4] << 8 | (long)buffer[5];
          totalIR += (irVal & 0x03FFFF);
          samplesRead++;
        }
      }

      if (samplesRead > 0) {
        irValue = totalIR / samplesRead;
        if (irValue < BRIGHTNESS_ADJUST_LOW_THRESH && currentBrightness <= (0xFF - 5)) {
          currentBrightness += 5;
        } else if (irValue > BRIGHTNESS_ADJUST_HIGH_THRESH && currentBrightness >= (0x00 + 5)) {
          currentBrightness -= 5;
        } else {
          brightnessOK = true;
        }
      } else {
        currentBrightness += 5;
      }
    }
    ledBrightness = currentBrightness;
    
    struct_status_packet statusPkt;
    strcpy(statusPkt.message, "CAL_OK");
    esp_now_send(masterAddress, (uint8_t*)&statusPkt, sizeof(struct_status_packet));
  }

  writeRegister8(MAX30102_ADDRESS, MAX_REG_MODE_CONFIG, 0x80); 
  xSemaphoreGive(i2cMutex);
  xSemaphoreGive(serialMutex);
}

void setSensorState(bool state) {
  if (state == sensorsActive) return;
  if (state) {
    if (xSemaphoreTake(i2cMutex, portMAX_DELAY)) {
      writeRegister8(MPU6050_ADDRESS, MPU_REG_PWR_MGMT_1, 0x00);
      delay(5);
      writeRegister8(MAX30102_ADDRESS, MAX_REG_MODE_CONFIG, 0x03);
      writeRegister8(MAX30102_ADDRESS, MAX_REG_LED1_PA, ledBrightness);
      writeRegister8(MAX30102_ADDRESS, MAX_REG_LED2_PA, ledBrightness);
      writeRegister8(MAX30102_ADDRESS, MAX_REG_FIFO_WR_PTR, 0x00);
      writeRegister8(MAX30102_ADDRESS, MAX_REG_FIFO_RD_PTR, 0x00);
      xSemaphoreGive(i2cMutex);
    }
    xQueueReset(ppgQueue);
    timeOffset_us = esp_timer_get_time();
    lastSampleTime = 0;
    dataBatch.sample_count = 0; 
    sensorsActive = true;

  } else {
    sensorsActive = false;
    if (dataBatch.sample_count > 0) {
        dataBatch.battery_mv = batteryVoltage_mv;
        esp_now_send(masterAddress, (uint8_t*)&dataBatch, sizeof(dataBatch));
        dataBatch.sample_count = 0;
    }
    if (xSemaphoreTake(i2cMutex, portMAX_DELAY)) {
      writeRegister8(MPU6050_ADDRESS, MPU_REG_PWR_MGMT_1, 0x40);
      writeRegister8(MAX30102_ADDRESS, MAX_REG_MODE_CONFIG, 0x80);
      xSemaphoreGive(i2cMutex);
    }
  }
}

void OnDataRecv(const esp_now_recv_info_t * info, const uint8_t *incomingData, int len) {
  if (memcmp(info->src_addr, masterAddress, 6) != 0) return;
  if (len == sizeof(struct_cmd_packet)) {
    struct_cmd_packet cmd;
    memcpy(&cmd, incomingData, sizeof(cmd));

    if (cmd.command == '1') { setSensorState(true); lastSampleTime = 0; }
    else if (cmd.command == '0') { setSensorState(false); }
    else if (cmd.command == '3') { 
      setSensorState(false);
      runCalibration();
    }
  }
}

void OnDataSent(const wifi_tx_info_t* tx_info, esp_now_send_status_t status) {}

void setup() {
  pinMode(LED_BUILTIN, OUTPUT);
  digitalWrite(LED_BUILTIN, HIGH);
  Serial.begin(921600);
  
  setCpuFrequencyMhz(80); 
  btStop();                

  serialMutex = xSemaphoreCreateMutex();
  i2cMutex    = xSemaphoreCreateMutex();
  mpuMutex    = xSemaphoreCreateMutex();
  ppgQueue    = xQueueCreate(32, sizeof(PpgData));

  Wire.begin();
  Wire.setClock(400000);

  if (xSemaphoreTake(i2cMutex, portMAX_DELAY)) {
    digitalWrite(LED_BUILTIN, LOW); delay(250); digitalWrite(LED_BUILTIN, HIGH); delay(250);
    writeRegister8(MAX30102_ADDRESS, MAX_REG_MODE_CONFIG, 0x40);
    delay(100);
    writeRegister8(MAX30102_ADDRESS, MAX_REG_FIFO_WR_PTR, 0x00);
    writeRegister8(MAX30102_ADDRESS, MAX_REG_FIFO_RD_PTR, 0x00);
    
    writeRegister8(MAX30102_ADDRESS, MAX_REG_SPO2_CONFIG, 0x27);
    writeRegister8(MAX30102_ADDRESS, MAX_REG_FIFO_CONFIG, 0x3F);
    writeRegister8(MAX30102_ADDRESS, MAX_REG_LED1_PA, ledBrightness);
    writeRegister8(MAX30102_ADDRESS, MAX_REG_LED2_PA, ledBrightness);
    writeRegister8(MAX30102_ADDRESS, MAX_REG_MODE_CONFIG, 0x03);
    xSemaphoreGive(i2cMutex);
  }

  if (xSemaphoreTake(i2cMutex, portMAX_DELAY)) {
    digitalWrite(LED_BUILTIN, LOW); delay(250); digitalWrite(LED_BUILTIN, HIGH); delay(250);
    writeRegister8(MPU6050_ADDRESS, MPU_REG_PWR_MGMT_1, 0x00); delay(100);
    writeRegister8(MPU6050_ADDRESS, MPU_REG_CONFIG, 0x03);
    writeRegister8(MPU6050_ADDRESS, MPU_REG_SMPLRT_DIV, 0x13);
    writeRegister8(MPU6050_ADDRESS, MPU_REG_GYRO_CONFIG, 0x00);
    writeRegister8(MPU6050_ADDRESS, MPU_REG_ACCEL_CONFIG, 0x00);
    xSemaphoreGive(i2cMutex);
  }

  if (xSemaphoreTake(i2cMutex, portMAX_DELAY)) {
    writeRegister8(MPU6050_ADDRESS, MPU_REG_PWR_MGMT_1, 0x40);
    writeRegister8(MAX30102_ADDRESS, MAX_REG_MODE_CONFIG, 0x80);
    xSemaphoreGive(i2cMutex);
  }

  WiFi.mode(WIFI_STA);
  esp_wifi_set_channel(ESPNOW_CHANNEL, WIFI_SECOND_CHAN_NONE);
  esp_wifi_set_max_tx_power(ESPNOW_TX_POWER);
  esp_wifi_set_ps(WIFI_PS_NONE); 

  if (esp_now_init() != ESP_OK) { errorBlink(); }
  esp_now_register_send_cb(OnDataSent);
  esp_now_register_recv_cb(OnDataRecv);

  esp_now_peer_info_t peer{};
  memcpy(peer.peer_addr, masterAddress, 6);
  peer.channel = ESPNOW_CHANNEL;
  peer.encrypt = false;
  esp_now_add_peer(&peer);

  dataBatch.sample_count = 0; 
  dataBatch.battery_mv = 0;

  #if (portNUM_PROCESSORS > 1)
    xTaskCreatePinnedToCore(mpuTask, "MpuTask", 4096, NULL, 2, &mpuTaskHandle, 1);
    xTaskCreatePinnedToCore(ppgTask, "PpgTask", 4096, NULL, 3, &ppgTaskHandle, 1);
    xTaskCreatePinnedToCore(batteryTask, "BattTask", 2048, NULL, 1, &batteryTaskHandle, 0);
  #else
    xTaskCreate(mpuTask, "MpuTask", 4096, NULL, 2, &mpuTaskHandle);
    xTaskCreate(ppgTask, "PpgTask", 4096, NULL, 3, &ppgTaskHandle);
    xTaskCreate(batteryTask, "BattTask", 2048, NULL, 1, &batteryTaskHandle);
  #endif

  systemRunning = true;
  digitalWrite(LED_BUILTIN, LOW);
}

void loop() {
  if (systemRunning && (millis() - ledTimer > (ledState ? 150 : 1000))) {
    ledState = !ledState;
    digitalWrite(LED_BUILTIN, ledState);
    ledTimer = millis();
  }

  if (sensorsActive) {
    PpgData p;
    if (xQueueReceive(ppgQueue, &p, 0)) {
      
      float instantaneousFs = 0.0f;
      if (lastSampleTime > 0) {
        int64_t dt = p.timestamp - lastSampleTime;
        if (dt > 0) instantaneousFs = 1000000.0f / (float)dt;
      }
      lastSampleTime = p.timestamp;

      MpuData m;
      xSemaphoreTake(mpuMutex, portMAX_DELAY);
      m = mpuDataGlobal;
      xSemaphoreGive(mpuMutex);

      int idx = dataBatch.sample_count;
      dataBatch.samples[idx].timestamp_us = p.timestamp;
      dataBatch.samples[idx].red = (uint32_t)p.red;
      dataBatch.samples[idx].ir  = (uint32_t)p.ir;
      dataBatch.samples[idx].ax = m.ax; 
      dataBatch.samples[idx].ay = m.ay; 
      dataBatch.samples[idx].az = m.az;
      dataBatch.samples[idx].gx = m.gx;
      dataBatch.samples[idx].gy = m.gy; 
      dataBatch.samples[idx].gz = m.gz;
      dataBatch.samples[idx].instantaneousFs = instantaneousFs;
      
      dataBatch.sample_count++;

      if (dataBatch.sample_count >= SAMPLES_PER_PACKET) {
        dataBatch.battery_mv = batteryVoltage_mv;
        esp_now_send(masterAddress, (uint8_t*)&dataBatch, sizeof(dataBatch));
        dataBatch.sample_count = 0; 
      }
      
    } else {
      delay(2);
    }
  } else {
    lastSampleTime = 0;
    delay(10);
  }
}

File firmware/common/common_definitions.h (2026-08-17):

/**
 * @file common_definitions.h
 * @author Andrés Navarro
 * @brief Shared definitions and data structures for the SPEC-P6 ESP-NOW system.
 * @institution Universidad de Guadalajara (UdeG) - CUCEI
 * @date 2026
 */

#ifndef COMMON_DEFINITIONS_H
#define COMMON_DEFINITIONS_H

#include <stdint.h>

#define ESPNOW_CHANNEL 1
#define ESPNOW_TX_POWER 48

#define PPG_POLL_INTERVAL_MS 15

#define BATTERY_ADC_PIN A0
#define BATTERY_DIVIDER_RATIO 2.0f
#define BATTERY_UPDATE_INTERVAL_MS 15000UL

uint8_t masterAddress[] = {0x10, 0x51, 0xDB, 0x1A, 0x30, 0xF4};

uint8_t slave1Address[] = {0xE4, 0xB3, 0x23, 0xB5, 0xAE, 0xD0};
uint8_t slave2Address[] = {0xE4, 0xB3, 0x23, 0xB4, 0x8C, 0xAC};
uint8_t slave3Address[] = {0xE4, 0xB3, 0x23, 0xB5, 0x82, 0xB8};

uint8_t* slaveAddresses[] = { slave1Address, slave2Address, slave3Address };
const int numSlaves = sizeof(slaveAddresses) / sizeof(slaveAddresses[0]);

typedef struct __attribute__((packed)) struct_cmd_packet {
    char command;
} struct_cmd_packet;

#define SAMPLES_PER_PACKET 5

typedef struct __attribute__((packed)) struct_single_sample {
    uint64_t timestamp_us;
    uint32_t red;
    uint32_t ir;
    int16_t ax;
    int16_t ay;
    int16_t az;
    int16_t gx;
    int16_t gy;
    int16_t gz;
    float instantaneousFs;
} struct_single_sample;

typedef struct __attribute__((packed)) struct_data_packet {
    uint8_t sample_count;
    uint16_t battery_mv;
    struct_single_sample samples[SAMPLES_PER_PACKET];
} struct_data_packet;

typedef struct __attribute__((packed)) struct_status_packet {
    char message[16];
} struct_status_packet;

#endif

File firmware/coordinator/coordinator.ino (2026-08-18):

/**
 * @file master_node.ino
 * @author Andrés Navarro
 * @brief Master Node Firmware (Bridge) - SPEC-P6 System
 * @details Firmware for the ESP32 master node. It acts as a bridge, receiving 
 *          packed sensor data from the slave nodes via ESP-NOW and forwarding 
 *          it through serial communication to the Python interface. It also 
 *          handles broadcast commands and BIOPAC synchronization triggers.
 * @institution Universidad de Guadalajara (UdeG) - CUCEI
 * @date 2026
 */

#include <esp_now.h>
#include <WiFi.h>
#include <esp_wifi.h>
#include "common_definitions.h"

uint8_t broadcastAddress[] = {0xFF, 0xFF, 0xFF, 0xFF, 0xFF, 0xFF};
#define BIOPAC_PIN 2 
#define BAUD_RATE 921600

void OnDataSent(const wifi_tx_info_t* tx_info, esp_now_send_status_t status) {
  if (status != ESP_NOW_SEND_SUCCESS) {
    Serial.println("[ERROR] Fallo al enviar comando Broadcast.");
  }
}

void OnDataRecv(const esp_now_recv_info_t * info, const uint8_t *incomingData, int len) {
  char* slaveID = "Unknown";
  if (memcmp(info->src_addr, slave1Address, 6) == 0) slaveID = "Slave1";
  else if (memcmp(info->src_addr, slave2Address, 6) == 0) slaveID = "Slave2";
  else if (memcmp(info->src_addr, slave3Address, 6) == 0) slaveID = "Slave3";

  if (len == sizeof(struct_data_packet)) {
    struct_data_packet batchData;
    memcpy(&batchData, incomingData, sizeof(batchData));

    for (int i = 0; i < batchData.sample_count; i++) {
        struct_single_sample s = batchData.samples[i];
        Serial.printf("%s,%llu,%u,%u,%d,%d,%d,%d,%d,%d,%.6f,%u\n",
                      slaveID, s.timestamp_us, s.red, s.ir,
                      s.ax, s.ay, s.az, s.gx, s.gy, s.gz, s.instantaneousFs,
                      batchData.battery_mv);
    }
  }
  else if (len == sizeof(struct_status_packet)) {
    struct_status_packet status;
    memcpy(&status, incomingData, sizeof(status));
    if (strcmp(status.message, "CAL_OK") == 0) {
      Serial.printf("CAL_OK,%s\n", slaveID);
    }
  }
}

void broadcastCommand(char cmd) {
  struct_cmd_packet cmdPkt;
  cmdPkt.command = cmd;
  esp_now_send(broadcastAddress, (uint8_t *) &cmdPkt, sizeof(cmdPkt));
}

void setup() {
  Serial.begin(BAUD_RATE);
  pinMode(BIOPAC_PIN, OUTPUT);
  digitalWrite(BIOPAC_PIN, LOW); 

  WiFi.mode(WIFI_STA);
  esp_wifi_set_channel(ESPNOW_CHANNEL, WIFI_SECOND_CHAN_NONE);
  esp_wifi_set_max_tx_power(ESPNOW_TX_POWER);
  esp_wifi_set_ps(WIFI_PS_NONE);

  if (esp_now_init() != ESP_OK) return;

  esp_now_register_send_cb(OnDataSent);
  esp_now_register_recv_cb(OnDataRecv);

  esp_now_peer_info_t peerInfo = {};
  memcpy(peerInfo.peer_addr, broadcastAddress, 6);
  peerInfo.channel = ESPNOW_CHANNEL;
  peerInfo.encrypt = false; 
  esp_now_add_peer(&peerInfo);
}

void loop() {
  if (Serial.available() > 0) {
    char cmd = (char)Serial.read();
    if (cmd == '0' || cmd == '1' || cmd == '3') broadcastCommand(cmd);
    else if (cmd == 'B') digitalWrite(BIOPAC_PIN, HIGH);
    else if (cmd == 'b') digitalWrite(BIOPAC_PIN, LOW);
  }
}
